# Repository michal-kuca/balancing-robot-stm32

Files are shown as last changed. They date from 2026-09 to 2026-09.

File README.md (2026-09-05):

# Self-Balancing Two-Wheeled Robot

An inverted-pendulum robot that balances on two wheels using an IMU, a complementary filter, and a PID controller — built from scratch on an STM32F103 with a 3D-printed chassis.

<!-- Drag & drop robot_clip_small.mp4 here in the GitHub web editor to embed the demo clip -->

**Full demo video:** https://youtube.com/shorts/e7V2TYy4I70

## Overview

A two-wheeled robot is an inverted pendulum: inherently unstable, with an unstable pole at √(g/l) ≈ 8 s⁻¹ for this chassis geometry — left alone, any tilt error grows e-fold roughly every 0.12 s. The firmware closes the loop fast enough to catch it: it reads the MPU-6050 over I²C every 5 ms, fuses the accelerometer and gyroscope into a tilt-angle estimate with a complementary filter, runs a PID controller on the angle error, and drives two DC motors through a DRV8833 H-bridge using slow-decay PWM.

The robot balances indefinitely and recovers from small pushes.

## Hardware

| Component | Part | Role |
|---|---|---|
| MCU board | STM32F103 (Nucleo-F103RB pinout) | Runs the control loop |
| IMU | MPU-6050 | 3-axis accelerometer + 3-axis gyroscope, I²C |
| Motor driver | DRV8833 | Dual H-bridge, slow-decay PWM drive |
| Motors | 2× geared DC motors with encoders | Drive wheels (encoders wired, odometry planned) |
| Power | 2S 18650 pack (7.4 V nominal) | Motor supply |
| Chassis | 3D printed | Two-level frame, battery on top for a higher center of mass |

Wiring diagram: [`docs/wiring_diagram.png`](docs/wiring_diagram.png) (Fritzing source: [`docs/wiring.fzz`](docs/wiring.fzz))

## Control loop

Every 5 ms (200 Hz — comfortably above the ~100 Hz minimum the pendulum dynamics demand):

1. **Read** raw accelerometer and gyroscope data from the MPU-6050 over I²C.
2. **Fuse** into a tilt angle with a complementary filter:
   `angle = 0.98 · (angle + gyro·dt) + 0.02 · accel_angle`
   — the gyro provides fast, drift-prone dynamics; the accelerometer provides slow, noisy but drift-free correction.
3. **Filter** the gyro rate with a software low-pass (`gyro_f = 0.7·gyro_f + 0.3·gyro`) before it feeds the D-term, breaking a motor-vibration → gyro-noise → D-term feedback loop (see the debug log, entry 13).
4. **PID** on the angle error, with the integral state clamped for anti-windup and the output clamped to the valid PWM range.
5. **Drive** the motors in slow-decay mode: one bridge input held high, PWM = `period − duty` on the other. Slow decay was chosen after fast decay left a dead zone of ~60 % duty; it recovered nearly the full torque range (minimum effective duty dropped from 60 to 10 out of 99) and gives braking at standstill for free.
6. **Safety cutoff** past ±45° of tilt — beyond recovery, motors stop.

## Repository structure

```
├── Core/                  # Application code (main.c: control loop, filter, PID, motor drive)
├── Drivers/               # STM32 HAL and CMSIS (vendor code)
├── cmake/                 # Toolchain files
├── docs/
│   ├── DEBUGGING.md       # Full debug log — every fault, root cause, and fix
│   ├── wiring_diagram.png # Fritzing wiring diagram
│   └── wiring.fzz         # Fritzing source
├── CMakeLists.txt
└── robot_blink.ioc        # STM32CubeMX configuration
```

## Building and flashing

Requires the ARM GCC toolchain and STM32CubeCLT (build tested with CubeCLT 1.22.0).

```powershell
cmake --preset Debug
cmake --build build/Debug; if ($?) {
  STM32_Programmer_CLI.exe -c port=SWD freq=480 mode=UR reset=HWrst `
    -w build\Debug\robot_blink.elf -v -rst
}
```

The `if ($?)` gate matters: it prevents flashing a stale `.elf` when the build fails. Telemetry (angle, gyro, PID terms) prints over the ST-Link virtual COM port; a version marker in the print string confirms each flash actually took.

## What went wrong (and got fixed)

This project did not work on the first try, and the record of that is deliberately part of the repo: **[docs/DEBUGGING.md](docs/DEBUGGING.md)** logs 20 distinct faults from destroyed hardware to a one-line PWM bug that made one motor unable to reverse — each with symptom, root cause, fix, and the lesson extracted. Highlights:

- A loose battery wire touched the MCU and killed an entire board — leading to strict live-wire discipline and a battery master disconnect.
- Switching the H-bridge from fast to slow decay inverted the meaning of every PWM register write, spawning three separate bugs before every write site was audited.
- The D-term amplified motor vibration back into the motors through the gyro — a self-sustaining oscillation diagnosed from serial logs showing a stable angle alongside an alternating ±130 °/s gyro reading.

## Planned improvements

- Start the encoder timers (TIM3/TIM4 already configured) and add velocity feedback to stop slow drift-walking.
- Untethered operation from the battery via the board's VIN input.
- Tune with the MPU-6050's hardware DLPF instead of (or alongside) the software gyro filter.

## License

MIT

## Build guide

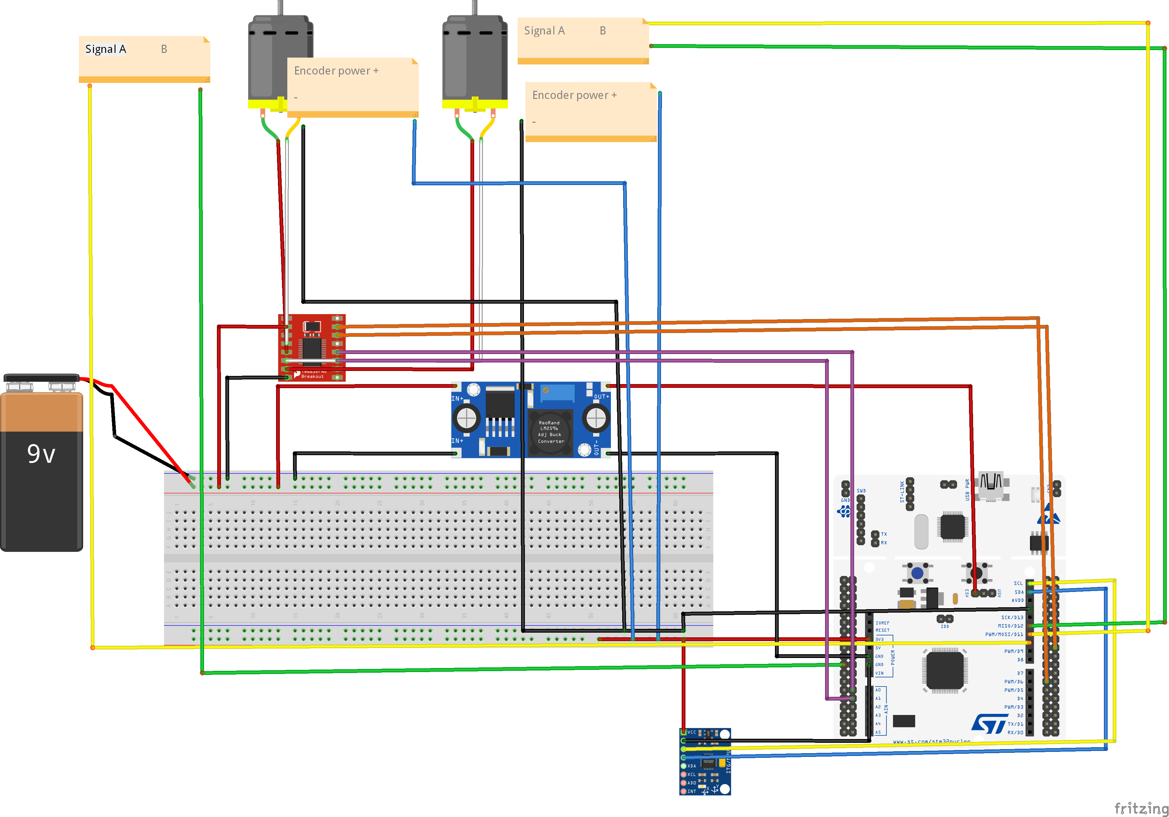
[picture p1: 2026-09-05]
docs/wiring_diagram.png

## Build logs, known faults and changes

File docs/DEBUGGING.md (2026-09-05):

# Debug Log — Self-Balancing Robot

A chronological record of every significant problem encountered during this build, its root cause, and the fix. Kept partly as engineering documentation, partly as proof that the robot did not work on the first try (it very much did not).

Hardware: STM32F103 (Nucleo-F103RB, later a clone board), MPU-6050 IMU, DRV8833 dual H-bridge, 2× geared DC motors with encoders, 2S 18650 battery pack.

---

## Part 1 — Hardware bring-up

### 1. Destroyed Nucleo board — loose battery wire touched the MCU
- **Symptom:** Smoke smell, STM32 chip too hot to touch, USB enumeration gone. Board completely dead.
- **Root cause:** A battery wire that was disconnected at one end brushed against the STM32's pins during rewiring. Battery voltage (far above the F103's ~4 V absolute maximum pin rating) went directly onto 3.3 V logic pins. The chip shorted internally and dumped the battery current as heat.
- **Fix:** Replacement board ordered. Before rebuilding, the breadboard was continuity-mapped with a multimeter to confirm no path existed from the battery rail to any logic pin except through the driver's VM input.
- **Lesson:** A live wire connected at only one end is the most dangerous thing on the bench. New rules adopted: (1) battery disconnected before *any* rewiring, no exceptions; (2) a wire is either fully connected or fully removed from the circuit; (3) a removable jumper/connector in the battery + line as a master disconnect. (The board's E5V/VIN external-power paths had also been damaged earlier, both reading ~2.2 V — the board was already wounded before the fatal incident.)

### 2. Power architecture revision
- **Symptom:** The buck converter + E5V power path caused repeated problems and was one adjustment mistake away from killing another board.
- **Decision:** Buck converter retired entirely. Motors powered directly from the 2S 18650 pack (7.4 V nominal); the Nucleo tethered via USB for all development and PID tuning. Untethered operation deferred to the very end via VIN (7–12 V input, onboard regulator — no external converter needed).
- **Lesson:** Don't debug a flaky control loop and a flaky power path at the same time. Sequence the risk: prove the control loop on rock-solid USB power first; untethering is then a ten-minute final step.

### 3. Motors dead — driver standby pin floating
- **Symptom:** Both motors completely unresponsive despite correct control signals; fault came and went between rebuilds.
- **Root cause:** The motor driver's standby/sleep pin was left floating instead of being tied high. A floating enable pin means the driver's outputs are (unpredictably) disabled.
- **Fix:** Standby pin wired to 3.3 V. Both motors immediately spun under static logic-level control (AIN1 high, AIN2 low), proving the full hardware chain end to end.
- **Lesson:** Enable/standby pins are the first thing to check when a driver ignores correct inputs. This same fault recurred multiple times during rewiring — it earns a permanent spot on the pre-flight checklist.

### 4. Intermittent faults — bad solder joints and Dupont jumpers
- **Symptom:** Connections that worked one session and failed the next; faults that moved when the harness was touched.
- **Root cause:** Cold/bad solder joints and worn Dupont jumper connections, especially on power lines.
- **Fix:** Solder braid used to clear clogged through-holes; power lines direct-soldered instead of running through header pins.
- **Lesson:** For anything carrying motor current, connectors are a liability. Solder the power path.

### 5. Clone board quirk — USB power path non-functional
- **Symptom:** SWD flashing failed with the board on USB only.
- **Root cause:** On the replacement (clone) board, the USB power path doesn't power the target properly — the MCU only runs with the battery connected.
- **Fix / workaround:** Established flashing ritual: battery connected, robot lying on its side (wheels free), then flash over SWD.
- **Lesson:** Clone boards save money and cost assumptions. Verify every power path on a new board before trusting it.

---

## Part 2 — Sensors and control

### 6. PID had no effect — hardcoded PWM override left in the loop
- **Symptom:** Tuning gains changed nothing; motors ran at a fixed speed regardless of tilt.
- **Root cause:** A leftover test block wrote a hardcoded PWM value to the compare registers *after* the PID output was applied, silently overriding the controller every cycle.
- **Fix:** Removed the override block.
- **Lesson:** Test scaffolding must be deleted, not commented "for later." One forgotten line invalidated an entire tuning session.

### 7. Wrong IMU axes and signs
- **Symptom:** Computed angle bore no resemblance to the physical tilt; filter output drifted or reacted to the wrong motion.
- **Root cause:** The accelerometer and gyro axis assignments (and their signs) didn't match the sensor's physical mounting orientation on the chassis.
- **Fix:** Corrected iteratively using live serial prints: tilt the robot a known direction, observe which raw axis responds and with what sign, fix the mapping, repeat.
- **Lesson:** Never assume the datasheet axes match your mounting. Calibrate the mapping empirically before trusting any fused output.

### 8. Complementary filter fighting itself — flipped gyro sign
- **Symptom:** The filtered angle was unstable/sluggish even though both raw sensors individually looked sane.
- **Root cause:** The gyro term entered the complementary filter with the wrong sign, so the gyro integration and the accelerometer correction pulled the estimate in opposite directions.
- **Fix:** Sign corrected; filter form verified as `angle = 0.98*(angle + gyro*dt) + 0.02*accel_angle` with the grouping intact.
- **Lesson:** In sensor fusion, a single sign error doesn't produce garbage — it produces something *almost* plausible, which is worse. Verify each input's sign independently before fusing.

### 9. Robot gave up past ~7° of tilt — duty overflow became "brake"
- **Symptom:** Correction worked for small tilts, then the wheels effectively stopped fighting once tilt exceeded roughly 7°.
- **Root cause:** The PID output mapped to a duty value that exceeded the timer period (99). Values above the period saturate the PWM at 100 %, which in the H-bridge input scheme in use turned the drive command into a brake/invalid state instead of maximum drive.
- **Fix:** Output clamped to the valid duty range before writing compare registers.
- **Lesson:** Every value written to a peripheral register needs an explicit range clamp. The hardware will not extrapolate your intent.

### 10. "Very weird" asymmetric behavior — motor A never reversed
- **Symptom:** Robot corrected properly in one direction and misbehaved in the other; one wheel behaved, the other didn't.
- **Root cause:** In motor A's direction logic, the "reverse" branch contained the *same two compare-register assignments* as the forward branch, just written in the opposite order. Reordering lines doesn't reorder signals — both branches drove the motor the same way. Motor B's branches were correctly mirrored, hence the asymmetry.
- **Fix:** Reverse branch rewritten so the channel held at 99 actually swaps between branches (that swap is what reverses the motor).
- **Lesson:** `grep` every `SET_COMPARE` and audit each line against one stated rule. Symmetric-looking code isn't necessarily symmetric.

### 11. Huge dead zone — fast decay vs. slow decay
- **Symptom:** Motors needed a duty of ~60/99 just to start moving, leaving almost no usable control range; small corrections were impossible and the robot "slapped" between overcorrections.
- **Root cause:** The bridge was being driven in fast-decay mode (PWM on one input, other low), where low duty cycles deliver very little average torque against motor friction.
- **Fix:** Switched to slow-decay drive (one input held high, PWM = `99 − duty` on the other). MIN_DUTY dropped from 60 to 10, recovering nearly the full control range. Bonus: at duty 0 slow decay brakes rather than coasts, so the robot stands "planted."
- **Lesson:** Decay mode is a control-system decision, not an implementation detail. It changes the torque-vs-duty curve — and it inverts the meaning of every compare value, so *every* register write (drive branches, zero case, safety stop, leftover test lines) must be converted to the new convention at once. Two follow-up bugs (#10 and a direction-convention flip) came from converting only part of them.

### 12. Sawtooth oscillation — integral windup and a clamp bug
- **Symptom:** Slow, growing lean followed by a sudden lurch, repeating — a sawtooth pattern in the output.
- **Root cause:** The integral term accumulated without proper limits (windup), and the clamp as first written didn't actually bound the stored integral state.
- **Fix:** Proper anti-windup: the integral accumulator itself clamped to a fixed range, not just the final output.
- **Lesson:** Clamping the output while letting the internal state grow unbounded just hides the windup until it's big enough to hurt. Clamp the state.

### 13. Violent vibration while "balanced" — D-term amplifying its own motor noise
- **Symptom:** Robot balanced (angle stable near zero) but vibrated aggressively. Serial log showed `comp_ang` ≈ 0 while the gyro read ±130 °/s alternating every line — the controller was reacting to vibration it was itself creating.
- **Root cause:** Motor vibration fed mechanical noise into the gyro; the D-term amplified it back into the motors — a self-sustaining feedback loop. Classic derivative-kick on a noisy measurement.
- **Fix:** (1) Software low-pass on the gyro: `gyro_f = 0.7*gyro_f + 0.3*gyro_Z_deg`, applied *after* `gyro_Z_deg` is assigned — the first attempt placed the filter line before the assignment, producing an uninitialized-use build warning; (2) Kd reduced to 0.4; (3) the standstill/rest-zone gate switched to use the filtered `gyro_f`.
- **Lesson:** The D-term is a noise amplifier by construction. If the plant vibrates, the derivative input must be filtered — and the log columns (stable angle + oscillating rate) are what distinguish controller-induced vibration from a real fall.

---

## Part 3 — Build & flashing toolchain

### 14. Code changes "not taking effect" — stale .elf flashed
- **Symptom:** Behavior identical after flashing, as if the new code never arrived.
- **Root cause(s):** Editor files not saved before building; and separately, a stuck GDB-server process holding a lock on the output file so the build silently reused the old `.elf`.
- **Fix:** Save-all before build; kill stuck GDB server processes; and the definitive countermeasure — a **version marker** (e.g. `V12`) in the serial print string, bumped on every flash, so a successful flash is *proven* on the serial monitor, never assumed.
- **Lesson:** "Flash succeeded" and "the code I just wrote is running" are different claims. The version marker collapses them into one observable fact.

### 15. Old firmware flashed even when the build failed
- **Symptom:** Build errors scrolled past, yet the flash step ran anyway — programming the previous `.elf`.
- **Root cause:** The build and flash commands were chained with `;` in PowerShell, which runs the second command unconditionally.
- **Fix:** Conditional chaining: `cmake --build build/Debug; if ($?) { <flash command> }` — flash only runs on build success.
- **Lesson:** In any scripted pipeline, later steps must be gated on earlier steps' success. `;` is not `&&`.

### 16. GDB server launching the wrong toolchain — two CubeCLT versions installed
- **Symptom:** Debug sessions failing in confusing ways.
- **Root cause:** STM32CubeCLT 1.21.0 and 1.22.0 were installed simultaneously; the GDB server resolved to the wrong installation.
- **Fix:** Old version uninstalled, paths pointed at 1.22.0.

### 17. Build broken after the CLT uninstall — stale CMake cache
- **Symptom:** After removing the old CubeCLT, the project no longer compiled — the compiler path baked into the CMake cache pointed at the deleted installation.
- **Fix:** Clean reconfigure: `Remove-Item -Recurse -Force build` followed by `cmake --preset Debug`.
- **Lesson:** CMake caches absolute toolchain paths. Any toolchain install/uninstall means a fresh configure.

### 18. ST-Link rejected — outdated probe firmware, then version mismatch
- **Symptom:** First the ST-Link was refused for being outdated; after updating its firmware via STM32CubeProgrammer, the VS Code GDB server refused it with a (misleading) "firmware upgrade required" — the server was now *older* than the probe firmware.
- **Fix:** ST-Link firmware updated via CubeProgrammer; then the VS Code STM32 extension and CubeCLT updated to match. In the interim, flashing went through the CubeProgrammer CLI, which accepted the new firmware.
- **Lesson:** The probe firmware, the GDB server, and the IDE extension are a matched set. Updating one end can break the other; keep them moving together.

### 19. "No device found" on SWD
- **Symptom:** GDB server started and reached the ST-Link, but the STM32 itself didn't answer on the SWD lines.
- **Diagnosis method:** Bare-board test — every wire off (battery, driver, IMU, encoders), USB only, then attempt connection. Connects → the chip is fine and something in the external wiring is loading the SWD/3V3 lines; still dead → check the CN2 jumpers, measure 3V3 rail, try another cable/port.
- **Lesson:** Binary-search the hardware: strip to minimum, confirm the core works, reconnect one subsystem at a time.

### 20. The reliable flash pipeline (final form)
Battery connected, robot on its side, from the project root:

```powershell
cmake --build build/Debug; if ($?) {
  & "C:\ST\STM32CubeCLT_1.22.0\STM32CubeProgrammer\bin\STM32_Programmer_CLI.exe" `
    -c port=SWD freq=480 mode=UR reset=HWrst `
    -w build\Debug\robot_blink.elf -v -rst
}
```

Then serial monitor at the configured baud rate, and check the version marker in the first print line.

---

## Meta-lessons from the whole project

1. **The code was never the asset at risk — the hardware was.** Firmware survives every disaster; boards don't. Discipline around live wires is worth more than any amount of clever code.
2. **One convention change touches everything.** Switching decay modes inverted the meaning of every PWM register write and spawned three separate bugs. Convention changes need a full audit, not a spot fix.
3. **Make success observable.** The version marker, the serial print columns, the multimeter checkpoints — every hard bug here fell to *making the invisible visible*, not to staring at code.
4. **Signs and axes are empirical facts,** established by experiment against the physical build, never assumed from a datasheet.

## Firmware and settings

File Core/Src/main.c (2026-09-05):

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
/* Includes ------------------------------------------------------------------*/
#include "main.h"
#include "stm32f1xx_hal.h"
#include "stm32f1xx_hal_i2c.h"
#include "stm32f1xx_hal_tim.h"
#include <math.h>
#include <stdint.h>
#include <stdio.h>
#include <string.h>
/* USER CODE BEGIN PD */
#define MIN_DUTY 9
/* USER CODE END PD */

I2C_HandleTypeDef hi2c1;

TIM_HandleTypeDef htim2;
TIM_HandleTypeDef htim3;
TIM_HandleTypeDef htim4;

UART_HandleTypeDef huart2;

/* USER CODE BEGIN PV */

uint32_t  time_old=0;
float target_ang=1.0;
float gyro_ang = 0; //angle derived from integration
float  comp_ang =0; //complimentary angle derived from both gyro and acceleration sensor

float Kp = 30;          // very stiff: full authority by ~3 deg
float Kd = 0.4;         // heavy damping to survive the stiffness
float Ki = 0;           // out of the picture entirely

float gyro_f = 0;

float integral =0;

//define integer 32bits
uint32_t loop_count=0;

    //CAlIBRATION OF ACCELEROMETER OFFSETS X Y AND Z:


    //DEFINE CONSTANTS AND DECLAER

/* USER CODE END PV */

void SystemClock_Config(void);
static void MX_GPIO_Init(void);
static void MX_USART2_UART_Init(void);
static void MX_I2C1_Init(void);
static void MX_TIM3_Init(void);
static void MX_TIM4_Init(void);
static void MX_TIM2_Init(void);
/* USER CODE BEGIN 0 */

//gyro around y axis is pitch in our case, around x roll and z yaw, x and z gyro should be zero
void readIMU(int16_t *aX, int16_t *aY, int16_t *aZ, int16_t *gX, int16_t *gY, int16_t *gZ){

    uint8_t accel_data[6];

    //read accel data
    HAL_I2C_Mem_Read(&hi2c1, 0x68<<1,0x3B, 1, accel_data, 6, 100);


    uint8_t gyro_data[6];

    //read gyro data
    HAL_I2C_Mem_Read(&hi2c1, 0x68<<1,0x43, 1, gyro_data, 6, 100);

*aX=(accel_data[0]<<8) |accel_data[1];

*aY=(accel_data[2] <<8) |accel_data[3];

*aZ=(accel_data[4] <<8) |accel_data[5];

*gX=(gyro_data[0] <<8) |gyro_data[1];

*gY=(gyro_data[2] <<8) |gyro_data[3];

*gZ=(gyro_data[4] <<8) |gyro_data[5];
}

float PID(float dt,float comp_ang,float gyro_Z_deg){

    //PID LOOP
     //1 is the balance point for the robot as center of mass is slightly in the back
    float error = target_ang - comp_ang;

    //Kp constant = stiffeness of the spring with respect to current error size
    float P=Kp*error;

    //Kd constant = stiffeness with respect to speed of error changing
    float D = Kd*(-gyro_Z_deg);

    //Ki stiffeness/ reaction to KI error

    


 if (error > 1.5f || error < -1.5f){
       integral += error*dt;
   if (integral > 60) integral = 60;
   if (integral < -60) integral = -60;
 }

    float I = Ki*integral;
    
    
    //adding response
    return(P+I+D);
}
    
/* USER CODE END 0 */

/**
  * @brief  The application entry point.
  * @retval int
  */
int main(void)
{

  /* MCU Configuration--------------------------------------------------------*/

  /* Reset of all peripherals, Initializes the Flash interface and the Systick. */





















































































































































































































































































  HAL_Init();

  /* Configure the system clock */
  SystemClock_Config();

  /* Initialize all configured peripherals */
  MX_GPIO_Init();
  MX_USART2_UART_Init();
  MX_I2C1_Init();
  MX_TIM3_Init();
  MX_TIM4_Init();
  MX_TIM2_Init();
  /* USER CODE BEGIN 2 */
  // wake up the MPU6050

  HAL_TIM_PWM_Start(&htim2, TIM_CHANNEL_1); //starts pin that connect to motor controller
  HAL_TIM_PWM_Start(&htim2, TIM_CHANNEL_2);

  HAL_TIM_PWM_Start(&htim2, TIM_CHANNEL_3); //starts pin that connect to motor controller
  HAL_TIM_PWM_Start(&htim2, TIM_CHANNEL_4);


  uint8_t wakeup = 0; //creates variable with assiged value 0

  uint8_t dlpf_setting= 3; // 44Hz

  HAL_I2C_Mem_Write(&hi2c1, 0x68<<1,0x1A,1,&dlpf_setting,1,100);

  // peripherrral name, mpu6050s address, register (power maagemet rergister), the adrress size (1 byte), poiter to the data im sending (wakekup varrriable is 0), how many bittes o send (1), timeoutt i ms (100ms++ imeou)
  HAL_I2C_Mem_Write(&hi2c1, 0x68<<1,0x6B,1,&wakeup,1,100); 


    //CALIBRATE GYRO ON STARTUP WHILE NOTHING IS TILTING
      //LOOP THAT TAKES 500 READINGS OF GYRO AND REMOVIES BIAS (IF FLAT THEN X AND Y)


  /* USER CODE END 2 */

  /* Infinite loop */
  /* USER CODE BEGIN WHILE */
  while (1)
    
  {
    uint32_t now=HAL_GetTick();

    float dt=(now-time_old)/ 1000.0; //.0 is important to keep it a float

    time_old=now;

    /* USER CODE END WHILE */

    /* USER CODE BEGIN 3 */

    
  //read accelerometer code

    //create buffer

      int16_t accel_X;

      int16_t accel_Y;

      int16_t accel_Z;

      int16_t gyro_X;

      int16_t gyro_Y;

      int16_t gyro_Z;

      readIMU(&accel_X, &accel_Y, &accel_Z, &gyro_X, &gyro_Y, &gyro_Z);

      float angle_accel;
    angle_accel= atan2(-accel_Y,-accel_X);

      float angle_accel2;
    angle_accel2= atan2(accel_Y,-accel_X);

      float angle_deg_accel;

    angle_deg_accel=(angle_accel*180)/3.14159;

      float angle_deg_accel2;
    angle_deg_accel2=(angle_accel2*180)/3.14159;

      float gyro_Z_deg; //gyro in deg/s

gyro_Z_deg = -gyro_Z/131.0f;                 // (your existing line, sign included)
gyro_f = 0.7f * gyro_f + 0.3f * gyro_Z_deg;  // smoothing AFTER the value exists //output for gyro gets sent as 131/degree of rotation

      //integrate to get angle purely based on gyro
      
       gyro_ang = gyro_ang + gyro_f*dt; 

      //integrate based on complimentary filter
      
        comp_ang = (comp_ang + (gyro_f*dt))*0.98 + angle_deg_accel*0.02;

      
      

    //print over UART
      //creates a buffer forr the text
    char msg[128]; 
      //replace each space by a number in order of X Y Z X...
    loop_count++;




      

    float output= -PID(dt,comp_ang,gyro_f);
    float mag = output; //mag is how much powerr is set ot motorr (magitude of pulse width)

    //absolute value
    if (mag<0){
    mag = -mag;
    }  
    //clamp magnitude 
    if (mag > 99){
      mag=90; //max duty is 99 but we'll clamp at 99
    }
    
    int duty=0;

    float err_now = comp_ang - target_ang;
        if (err_now > -2.5f && err_now < 2.5f && gyro_f > -40 && gyro_f < 40){
    duty = 0;
} else {
        duty = (int)(MIN_DUTY + mag * (99.0f - MIN_DUTY) / 90.0f);
    }




    if (mag<5){
     duty =0;
    }
    else{
    duty = (int)(MIN_DUTY + (mag - 5) * (99.0 - MIN_DUTY) / 85.0);
    }
    //safety switch (more than 45 means robot cant be saved so just stop spinning)

    if (comp_ang>45 || comp_ang<-45){
      __HAL_TIM_SET_COMPARE(&htim2, TIM_CHANNEL_1, 99);
      __HAL_TIM_SET_COMPARE(&htim2, TIM_CHANNEL_2, 99);
      __HAL_TIM_SET_COMPARE(&htim2, TIM_CHANNEL_3, 99);
     __HAL_TIM_SET_COMPARE(&htim2, TIM_CHANNEL_4, 99);
    }
        
    //if output is positive, spin forwards
    else{
      if (output>=0){
        __HAL_TIM_SET_COMPARE(&htim2, TIM_CHANNEL_2, 99-duty); //timer 2 chanel 1, PWM and two
        __HAL_TIM_SET_COMPARE(&htim2, TIM_CHANNEL_1, 99);
      //spin backwards
      }
      else if (output<0){
        __HAL_TIM_SET_COMPARE(&htim2, TIM_CHANNEL_1, 99-duty); //timer 2 chanel 1, PWM and two
        __HAL_TIM_SET_COMPARE(&htim2, TIM_CHANNEL_2, 99);
      }

      //motor B
      if (output>=0){
        __HAL_TIM_SET_COMPARE(&htim2, TIM_CHANNEL_4, 99-duty); //timer 2 chanel 1, PWM and two
        __HAL_TIM_SET_COMPARE(&htim2, TIM_CHANNEL_3, 99);
      }
      else if (output<0){
        __HAL_TIM_SET_COMPARE(&htim2, TIM_CHANNEL_3, 99-duty); //timer 2 chanel 1, PWM and two
        __HAL_TIM_SET_COMPARE(&htim2, TIM_CHANNEL_4, 99);
      }
    }
    if (loop_count>=50){ //every 50 loops (250 ms with 5ms delay)
      loop_count=0; //reset loop count
    
    //builds the strink to send over uart

sprintf(msg,"V12 a:%d c:%d g:%d out:%d d:%d\r\n",
    (int)angle_deg_accel,(int)comp_ang,(int)gyro_f,(int)output,(int)duty);

    //sprintf(msg,"Angle(acc): %d Angle(gyr): %d Angle_comp: %d inst_angle_gyro: %d (deg/s)\r\n ",(int)angle_deg_accel,(int)gyro_ang, (int)comp_ang, (int)gyro_Z_deg);

      //Send text over UART:
      //configured uart, text to send in bites, length of message (string), timeout if no response
      HAL_UART_Transmit(&huart2, (uint8_t*)msg, strlen(msg), 100);

    } //only prints 4 times/s

    HAL_Delay(5); //only 5ms delay to make frequency 200HZ


    //read values when lying in each of 6 axis to get offset in acceleration


    //values/16384 * 9.81 = accel in m/s^2


    //make complementary filter out of gyro and accel angle
    //0.98*(gyro current angle + dt*gyro(instantaneous))+0.02*(tan2(xaccel, zaccel)*180/3.14159)   we converted from rad to degrees

    //atan2 is needed to distinguish between - angles and + angles




    //PID loop and 3 constants: actually control the wheels and send commands
  /* USER CODE END 3 */
}
}
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


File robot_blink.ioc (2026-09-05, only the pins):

Mcu.UserName=STM32F103RBTx
PA0-WKUP.Signal=S_TIM2_CH1_ETR
PA1.Signal=S_TIM2_CH2
PA13.GPIO_Label=TMS
PA13.Signal=SYS_JTMS-SWDIO
PA14.GPIO_Label=TCK
PA14.Signal=SYS_JTCK-SWCLK
PA2.GPIO_Label=USART_TX
PA2.Signal=USART2_TX
PA3.GPIO_Label=USART_RX
PA3.Signal=USART2_RX
PA5.GPIO_Label=LD2 [Green Led]
PA5.Signal=GPIO_Output
PA6.Signal=S_TIM3_CH1
PA7.Signal=S_TIM3_CH2
PB10.Signal=S_TIM2_CH3
PB11.Signal=S_TIM2_CH4
PB3.GPIO_Label=SWO
PB3.Signal=SYS_JTDO-TRACESWO
PB6.Signal=S_TIM4_CH1
PB7.Signal=S_TIM4_CH2
PB8.Signal=I2C1_SCL
PB9.Signal=I2C1_SDA
PC13-TAMPER-RTC.GPIO_Label=B1 [Blue PushButton]
PC13-TAMPER-RTC.Signal=GPXTI13
PC14-OSC32_IN.Signal=RCC_OSC32_IN
PC15-OSC32_OUT.Signal=RCC_OSC32_OUT
PD0-OSC_IN.Signal=RCC_OSC_IN
PD1-OSC_OUT.Signal=RCC_OSC_OUT

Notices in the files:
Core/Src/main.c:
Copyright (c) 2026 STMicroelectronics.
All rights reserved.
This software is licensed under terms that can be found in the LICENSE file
